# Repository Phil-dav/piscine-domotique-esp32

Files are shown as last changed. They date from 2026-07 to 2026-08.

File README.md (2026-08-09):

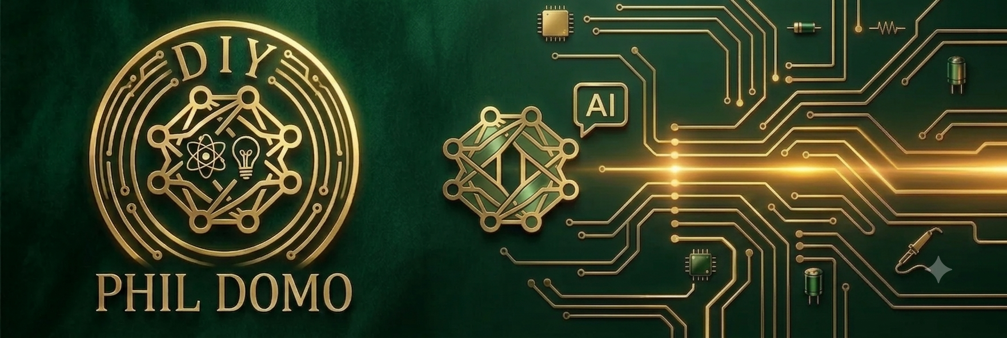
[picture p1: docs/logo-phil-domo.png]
Logo Phil Domo


# Gestion de filtration piscine — ESP32 / Rust





Système domotique embarqué qui pilote la pompe de filtration d'une piscine
familiale : température de l'eau, sécurités matérielles, planification
automatique, tableau de bord web, suivi cloud. Écrit en Rust sur ESP32
(`esp-idf-hal` / `esp-idf-svc`), portage et évolution d'un projet
C++/PlatformIO de référence.

## Sommaire

- [Aperçu](#aperçu)
- [Fonctionnalités](#fonctionnalités)
- [Architecture matérielle](#architecture-matérielle)
- [Organisation des fichiers](#organisation-des-fichiers)
- [Démarrage](#démarrage)
- [Tableau de bord web](#tableau-de-bord-web)
- [État du projet](#état-du-projet)
- [Licence](#licence)

## Aperçu

Le montage pilote une pompe de filtration selon trois modes sélectionnables
par un interrupteur physique — **AUTO** (durée de filtration calculée selon la
température de l'eau, dans une plage horaire configurable), **MANUEL**
(marche/arrêt à la demande) et **OFF** — avec un jeu de sécurités matérielles
(niveau d'eau, défaut moteur, anti-gel, canicule) qui prennent le pas sur
n'importe quel mode en cas de besoin. Un serveur web embarqué directement sur
l'ESP32 sert un tableau de bord en temps réel, sans dépendance à un service
externe pour fonctionner au quotidien.

## Fonctionnalités

- **Trois modes de fonctionnement** (interrupteur physique 3 positions) : AUTO,
  MANUEL (bouton ou page web), OFF.
- **Sécurités matérielles** : niveau d'eau, défaut moteur (disjoncteur),
  anti-gel, canicule, anti-claquement du relais (protection contre un cyclage
  trop rapide).
- **Task Watchdog** : tout blocage de plus de 5 s de la boucle principale
  déclenche un redémarrage automatique et journalisé, plutôt qu'un blocage
  total silencieux.
- **Tableau de bord web embarqué**, servi directement par l'ESP32 : température
  eau/air, humidité, état pompe, mode, position GPS, tension batterie, timeline
  colorée des modes de la journée (avec trace réelle de la marche pompe),
  marche forcée, réglage de la plage horaire, consultation des journaux
  (sessions pompe, bilans journaliers, alertes).
- **Journalisation persistante** (NVS) : sessions pompe, bilans journaliers,
  alertes, et compteurs du jour — survivent aux redémarrages.
- **Suivi cloud** vers [Adafruit IO](https://io.adafruit.com) : envoi groupé de
  toutes les mesures en une seule requête HTTP par cycle, dans un fil
  d'exécution dédié, jamais dans la boucle principale surveillée par le
  watchdog.
- **Horodatage GPS avec repli NTP** : heure fiable même sans réseau Wi-Fi.
- **Suivi de l'alimentation batterie/solaire** (en cours de câblage) : deux
  ponts diviseurs de tension pour surveiller la batterie 12V et la sortie
  régulée 5V d'un contrôleur de charge solaire.

## Architecture matérielle

| Bus / broche | Composant | Rôle |
| --- | --- | --- |
| I2C (GPIO21 SDA, GPIO22 SCL, 400 kHz) | AHT10 (0x38) | Température / humidité air |
| I2C | PCF8574 (0x21) | Expandeur de broches (relais, boutons, interrupteur de mode) |
| I2C | SSD1306 (0x3C) | Écran OLED de diagnostic |
| 1-Wire (GPIO4) | DS18B20 | Température de l'eau |
| UART2 (GPIO16 RX) | Module GPS | Horodatage et coordonnées |
| ADC1 (GPIO34) | Détecteur de niveau | Sécurité niveau d'eau |
| ADC1 (GPIO32, GPIO35) | Ponts diviseurs | Tension batterie 12V / sortie solaire 5V |

Détail du câblage du PCF8574 : P0 pilote le relais pompe, P3 le relais de
défaut système, P4/P5/P6 lisent respectivement le bouton écran et
l'interrupteur de mode (MANU/AUTO), P7 lit le retour de défaut moteur.

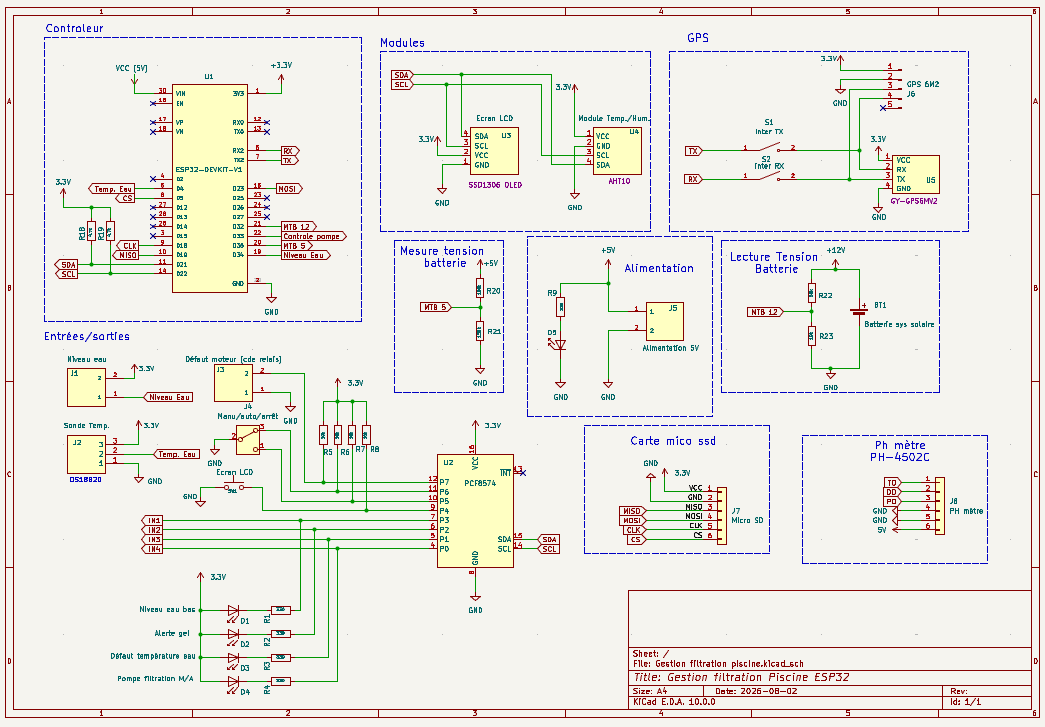
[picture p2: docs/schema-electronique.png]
Schéma électronique du montage


Schéma KiCad complet du montage. Il inclut des blocs anticipés dans la
conception (carte micro SD, pH-mètre PH-4502C, interrupteurs de logs série)
qui sont déjà câblés mais **pas encore pris en charge par le firmware
actuel** — schéma établi en amont de la réalisation, comme il est d'usage en
électronique.

Une [version vectorielle au format SVG](https://raw.githubusercontent.com/Phil-dav/piscine-domotique-esp32/main/docs/Gestion%20filtration%20piscine.svg)
est également disponible. Elle s'ouvre en plein écran dans le navigateur et se
zoome avec **Ctrl + molette** sans aucune perte de qualité, ce qui permet de lire
les références et les valeurs de chaque composant.

## Organisation des fichiers

Tout part de `main.rs`, qui orchestre les modules ci-dessous (capteurs, sécurité,
réseau, persistance) à chaque tour de la boucle principale.

```text
src/
├── main.rs             Point d'entrée : boucle principale, initialisation matérielle,
│                        orchestration de tous les modules ci-dessous
├── config.rs            Identifiants et réglages (Wi-Fi, Adafruit IO, broches) — non
│                        suivi par Git, voir config.example.rs pour le modèle
├── config.example.rs    Modèle de config.rs à copier et remplir localement
│
├── Capteurs
│   ├── aht10.rs          Driver du capteur AHT10 (température/humidité air)
│   ├── ds18b20.rs        Driver de la sonde DS18B20 (température eau, 1-Wire)
│   ├── gps.rs            Lecture des trames NMEA du module GPS
│   ├── niveau_eau.rs     Détection du niveau d'eau (sécurité)
│   └── batterie.rs       Lecture des tensions batterie/solaire (ADC)
│
├── Pilotage
│   ├── pcf8574.rs        Pilotage de l'expandeur I2C (relais, boutons, interrupteur)
│   ├── pompe.rs          État de la pompe (marche/arrêt, anti-claquement, compteurs)
│   ├── boost.rs          Marche/arrêt forcée temporaire
│   ├── filtration_auto.rs  Calcul de la durée de filtration (mode AUTO)
│   ├── securite.rs       Détection défaut moteur
│   └── historique_modes.rs  Historique coloré des modes pour la timeline du dashboard
│
├── Stockage et journalisation
│   ├── stockage.rs       Accès générique à la mémoire NVS (clé/valeur)
│   ├── journal.rs        Journaux persistés : sessions pompe, bilans, alertes
│   └── temps.rs          Conversion d'heure (UTC vers Europe/Paris, DST)
│
├── Réseau et interface
│   ├── wifi.rs           Connexion Wi-Fi
│   ├── web_server.rs     Serveur web embarqué : routes HTTP et API du dashboard
│   ├── adafruit_io.rs    Envoi des mesures vers Adafruit IO (cloud)
│   ├── etat_partage.rs   État partagé entre la boucle principale et le serveur web
│   ├── ecran.rs          Affichage sur l'écran OLED de diagnostic
│   ├── index.html        Page du tableau de bord
│   └── script.js         Logique JavaScript du tableau de bord
```

## Démarrage

1. Copier `src/config.example.rs` vers `src/config.rs` et y renseigner tes
   propres identifiants (Wi-Fi, clé Adafruit IO si tu utilises ce service —
   sinon laisse les valeurs par défaut, le programme continue de fonctionner
   sans Wi-Fi ni cloud).
2. Toolchain ESP-IDF `v5.5.3`, cible `xtensa-esp32-espidf` (voir
   `rust-toolchain.toml` et `.cargo/config.toml`).
3. `cargo check` pour vérifier, `cargo run` pour flasher (nécessite
   `espflash`).

## Tableau de bord web

Servi directement par l'ESP32 sur le réseau local (pas de service externe
requis) : mesures en temps réel, contrôle de la pompe et du mode, timeline
colorée de la journée, historique des sessions/alertes, réglage de la plage
de filtration.

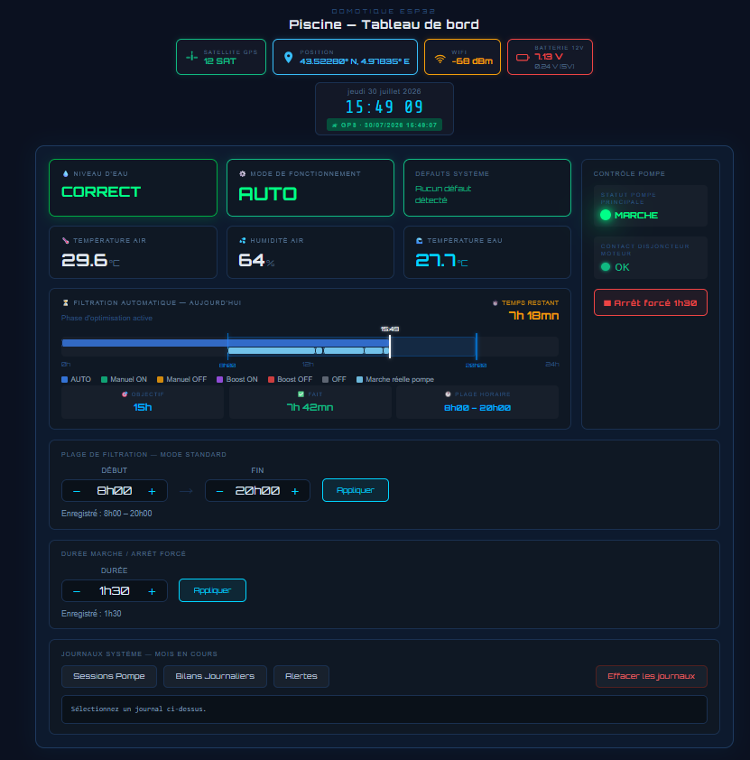
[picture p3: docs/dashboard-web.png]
Tableau de bord web


## État du projet

En développement actif — les fonctionnalités listées ci-dessus sont
opérationnelles et testées en conditions réelles. Chantiers en cours ou à
venir : carte SD pour un historique complet, capteur de courant sur
l'alimentation pompe, alarme de température du coffret électrique, alertes
push (ntfy.sh).

## Licence

Projet personnel, à but pédagogique et domestique.

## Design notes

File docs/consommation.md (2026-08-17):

# Bilan de consommation électrique

> Estimations basées sur les datasheets officiels des composants (sources
> citées pour chaque valeur), pas des mesures physiques. À confirmer un jour
> au multimètre/pince ampèremétrique si une vérification réelle est utile.

## Contexte

Suite à la conversion du PCB en 3,3V pour tout sauf le VIN de l'ESP32 et le
module 4 relais (voir la mémoire du projet sur le sujet), ce document répond à
la question : le régulateur 3,3V embarqué de l'ESP32 a-t-il assez de marge
pour alimenter tous les nouveaux composants raccordés dessus (écran OLED,
GPS, AHT10, PCF8574 et ses résistances/LED) ?

**Point important** : le rail 3,3V n'est pas une alimentation indépendante —
il est produit par le régulateur embarqué de l'ESP32 à partir du 5V d'entrée
(VIN). Le courant du rail 3,3V se retrouve donc intégralement dans le courant
tiré sur le 5V d'entrée (régulateur linéaire : courant d'entrée ≈ courant de
sortie, l'écart de tension est juste dissipé en chaleur). Le total réel à la
source d'alimentation 5V externe est donc : **module relais (direct 5V) +
courant du rail 3,3V (via le régulateur)** — pas une simple addition 5V + 3,3V
en parallèle.

## Rail 3,3V (via le régulateur embarqué de l'ESP32)

| Composant | Consommation | Source |
|---|---|---|
| ESP32-WROOM-32 (le module lui-même) | ~80-100 mA en fonctionnement normal, jusqu'à **240 mA en pointe** (émission Wi-Fi) | [Datasheet ESP32-WROOM-32](https://www.mouser.com/datasheet/2/891/esp-wroom-32_datasheet_en-1223836.pdf) |
| Module GPS GY-NEO6MV2 (NEO-6M) | ~45 mA en poursuite (jusqu'à ~67 mA au démarrage à froid) | [datasheethub.com](https://www.datasheethub.com/gy-neo6mv2-flight-control-gps-module/) |
| Écran OLED SSD1306 128×64 | ~20-25 mA typique (jusqu'à ~50 mA si affichage presque entièrement allumé) | [Datasheet SSD1306 (Adafruit)](https://cdn-shop.adafruit.com/datasheets/SSD1306.pdf) |
| AHT10 | ~1 mA max en mesure (négligeable, µA au repos) | [Datasheet AOSONG/ASAIR](https://server4.eca.ir/eshop/AHT10/Aosong_AHT10_en_draft_0c.pdf) |
| PCF8574 (puce elle-même) | ~10 µA en veille (négligeable) | [Datasheet TI](https://www.ti.com/product/PCF8574) |
| 4 résistances de tirage P4-P7 (10 kΩ vers 3,3V) | 0,33 mA chacune → **1,3 mA** au total | Calcul (loi d'Ohm, valeurs confirmées dans le schéma KiCad) |
| 4 LED D1-D4 (résistances série R1-R4 = 330 Ω) toutes allumées ensemble | ~4 mA chacune → **~16 mA** au total | Calcul (loi d'Ohm, seuil LED estimé ~2V) |

**Sous-total rail 3,3V** : ~190 mA en fonctionnement normal, jusqu'à **~330 mA en pointe** (Wi-Fi + GPS + écran chargé simultanément).

## Rail 5V direct (ne passe pas par le régulateur 3,3V)

| Composant | Consommation | Source |
|---|---|---|
| Module 4 relais (Songle SRD-05VDC-SL-C), les 4 énergisés en même temps | 71,4 mA par relais → **~285 mA** au total | [Datasheet SRD-05VDC-SL-C](https://www.circuitbasics.com/wp-content/uploads/2015/11/SRD-05VDC-SL-C-Datasheet.pdf) |

En pratique, il est rare que les 4 relais soient activés exactement en même
temps (pompe + ventilation coffret sont les deux usages prévus à ce jour) —
cette valeur est un plafond, pas la consommation habituelle.

## Total à la source d'alimentation 5V externe

| Scénario | Calcul | Total |
|---|---|---|
| Fonctionnement normal | 3,3V (~190 mA, via régulateur) + relais (2 relais actifs, ~140 mA) | **~330 mA** |
| Pire cas (tout en pointe en même temps) | 3,3V (~330 mA) + relais (4 actifs, ~285 mA) | **~615 mA** |

## Marge disponible

Le régulateur 3,3V embarqué de l'ESP32 (selon le modèle de carte, à vérifier
par le marquage sur le petit boîtier près du connecteur USB) :

- **AMS1117-3.3** (le plus courant) : 1 A max → la pointe de ~330 mA sur le
  rail 3,3V reste à **33% de sa capacité**, largement confortable.
- **ME6211C33** (SOT23-5, sur certains clones plus compacts) : 500 mA max →
  ~330 mA en pointe représente **66% de sa capacité** — toujours dans les
  clous, marge plus serrée.

**Conclusion (analysée le 04/08/2026)** : marge confortable dans les deux cas
pour la configuration actuelle. Pas besoin d'une alimentation 3,3V externe
séparée pour l'instant. À revérifier si un composant supplémentaire important
est ajouté un jour (le pH-mètre PH-4502C, par exemple, consomme lui-même très
peu — quelques mA — donc ne changerait pas cette conclusion).

Pensez aussi à vérifier que votre bloc d'alimentation 5V externe (celui qui
alimente le J5 "Alimentation 5V") est bien dimensionné pour au moins ~700 mA
avec de la marge, pour couvrir le pire cas ci-dessus sans être à sa limite.

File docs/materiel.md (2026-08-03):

# Matériel utilisé

Une fiche par composant du montage : rôle dans le projet, lien vers la fiche
technique (datasheet) officielle du fabricant, et photo/schéma quand disponible.

Voir aussi le [schéma électronique complet](schema-electronique.png) et le
[tableau d'architecture matérielle](../README.md#architecture-matérielle) dans le
README, plus synthétique.

## AHT10

**Rôle** : température et humidité de l'air (I2C, adresse 0x38).

**Fiche technique** : [AHT10 — datasheet (PDF)](https://components101.com/sites/default/files/component_datasheet/AHT10.pdf)

## PCF8574

**Rôle** : expandeur de broches I2C (adresse 0x21) — pilotage du relais pompe et
du relais de défaut système, lecture des boutons et de l'interrupteur de mode,
lecture du défaut moteur.

**Fiche technique** : [PCF8574 — datasheet officielle NXP (PDF)](https://www.nxp.com/docs/en/data-sheet/PCF8574_PCF8574A.pdf)

## SSD1306

**Rôle** : contrôleur de l'écran OLED de diagnostic (I2C, adresse 0x3C).

**Fiche technique** : [SSD1306 — datasheet officielle Solomon Systech (PDF)](https://cdn-shop.adafruit.com/datasheets/SSD1306.pdf)

## DS18B20

**Rôle** : sonde de température de l'eau (bus 1-Wire, GPIO4).

**Fiche technique** : [DS18B20 — page produit et datasheet officielle Analog Devices/Maxim](https://www.analog.com/en/products/ds18b20.html)

## Module GPS — GY-NEO6MV2 (puce u-blox NEO-6M)

**Rôle** : horodatage et coordonnées GPS (UART2, GPIO16 RX).

Carte de rupture (breakout board) générique GY-NEO6MV2/GY-GPS6MV2, basée sur la
puce u-blox NEO-6M — existe en variante 4 ou 5 broches (la 5ᵉ broche ajoute
généralement une sortie PPS, non utilisée dans ce projet).

**Fiche technique** : [NEO-6 — datasheet officielle u-blox (PDF)](https://content.u-blox.com/sites/default/files/products/documents/NEO-6_DataSheet_(GPS.G6-HW-09005).pdf)

## Détecteur de niveau d'eau — poire à flotteur, contact sec

**Rôle** : sécurité niveau d'eau (ADC1, GPIO34).

Poire de niveau à flotteur, contact sec NO/NC (normalement ouvert/fermé) — composant
purement mécanique, pas d'électronique embarquée. Contact ouvert/fermé lu côté
firmware via une lecture ADC avec seuils et hystérésis (`niveau_eau.rs`), le même
principe s'applique quel que soit le modèle exact choisi. Pas de référence précise
retenue pour l'instant — n'importe quelle poire générique à contact sec NO/NC fait
l'affaire (ex. modèles disponibles chez ManoMano, Assainipompes.fr,
Pompes-direct.com).

**Fiche technique** : composant mécanique générique, pas de datasheet dédiée
nécessaire — juste vérifier le type de contact (NO/NC) et le courant max supporté
(5A largement suffisant, le contact ne pilote qu'une entrée logique).

## PH-4502C

**Rôle** : mesure du pH de l'eau — module **amovible**, pas branché en permanence
(voir la mémoire du projet : vérification ponctuelle sous tension, résistance de
tirage 200 kΩ-1 MΩ prévue sur l'ADC pour détecter branchement/débranchement). Déjà
en main (testé avec Arduino Uno), câblage sur l'ESP32 et mise à jour du schéma
électronique restants à faire.

Alimentation 5±0,2V, sortie analogique 0-5V (pont diviseur nécessaire vers l'ADC
ESP32, limité à 3,3V), électrode à connecteur BNC, 2 potentiomètres de calibration
à bord. Temps de réponse ≤ 5s, stabilisation ≤ 60s.

**Fiche technique** : [page produit officielle diymore.cc](https://www.diymore.cc/products/diymore-liquid-ph-value-detection-detect-sensor-module-monitoring-control-for-arduino-m) —
voir aussi ce [guide d'utilisation et de calibration détaillé](https://raaflahar.medium.com/ph-4502c-sensor-diymore-how-to-use-and-calibrate-using-arduino-uno-r3-3afc2b96631).

**Photo** : test avec Arduino Uno, voir `c:\rust\Images vidéos\PH metre arduino.jpeg`.

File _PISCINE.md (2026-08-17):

# Automate de piscine — projet principal

Paquet : `pcf8574`
Carte : ESP32 classique (bicœur, Xtensa), cible `xtensa-esp32-espidf`.
Port série : **COM4**

## Ce que fait ce dossier

Le pilotage complet de la filtration : lecture des températures (eau et air),
calcul du temps de filtration nécessaire, commande du relais de pompe, sécurités
(niveau d'eau, défaut moteur, anti-gel, canicule), écran embarqué, horloge GPS,
tableau de bord web servi par la carte elle-même, et envoi vers Adafruit IO.

C'est le seul dossier en production : il tourne en permanence.

## Commandes

```
flash piscine      # téléverse (C:\rust\3, cargo run)
connect piscine    # capture le port série vers C:\rust\3\logs
```

Les journaux sont écrits en deux fichiers par capture :
`log_piscine_<date>_fonctionnement.txt` (lignes `I`) et `..._defauts.txt`
(lignes `W` et `E`).

## À savoir avant de toucher au code

**Incrémenter `VERSION_FIRMWARE` dans `src/config.rs` avant chaque flash.** C'est
le seul moyen de savoir, en lisant un journal, quelle version tournait.

**Un arrêt d'urgence câblé, indépendant de l'ESP32**, coupe l'alimentation du
relais de puissance. Les délais et sécurités logiciels relèvent donc du confort
de fonctionnement, pas de la sécurité des personnes.

`src/config.rs` contient les identifiants Wi-Fi et les clés Adafruit : il n'est
pas versionné. `config.example.rs` en tient lieu de modèle.

## Documentation

- `README.md` — installation, matériel, mise en route
- `docs/etat-projet.md` — état des lieux, réécrit à chaque bilan
- `docs/logique-pilotage-pompe.md` — la pyramide de priorité des décisions
- `docs/these-wifi-esp32*.md` — le récit de l'enquête sur l'instabilité réseau
- `.claude/skills/` — procédures de compilation, de diagnostic et de portage

## État au 16/08/2026

Version **1.9** en service. La **2.0** est compilée et vérifiée mais **pas encore
flashée** : elle corrige la reconnexion Wi-Fi, qui n'exécutait rien
(`disconnect()` manquant avant `connect()`), et espace le journal série de 2 s à
10 s avec déclenchement immédiat sur changement d'état.

Voir `c:\rust\5` — l'espion Wi-Fi, construit pour observer cette carte depuis
l'extérieur.

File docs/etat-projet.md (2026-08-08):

# État du projet — point du 08/08/2026

> Ce fichier est mis à jour automatiquement à chaque fois que je fais un point
> avec l'utilisateur sur l'avancement du projet. Le contenu ci-dessous est
> remplacé intégralement à chaque nouveau point, ce n'est pas un historique.

## La journée du 08/08 : enquête Wi-Fi complète

Toute la session a été consacrée à une panne réseau, puis à sa cause racine.
Trois versions de firmware ont été flashées dans la journée (1.1, 1.2, 1.3).

### La panne constatée

À 09h48, le signal chute à -77 dBm. Suivent **1h30 de dashboard totalement
injoignable**, avec 5 réinitialisations complètes du pilote Wi-Fi qui ne
rétablissent rien. La Livebox voyait pourtant la carte comme connectée, avec
son IP. Seul un **reset manuel à 11h29** a rétabli le service.

Point important : ce n'était **pas** un plantage du firmware. Aucun
redémarrage, aucun panic, RAM stable (142-163 Ko), capteurs actifs pendant
tout l'épisode.

### Cause racine n°1 — le contrôle de santé Wi-Fi était trop faible

`is_connected()` d'esp-idf-svc ne reflète **que l'association 802.11** : un
simple drapeau alimenté par les événements du pilote. Il ne prouve à aucun
moment qu'un paquet circule.

Le piège : la logique de reconnexion de `main.rs` est gardée par
`if wifi_connecte { ... } else { ...reconnexion... }`. Tant que
`is_connected()` répond `true`, **aucun mécanisme de secours ne peut se
déclencher**. La carte pouvait donc rester indéfiniment « associée mais
morte », ce qui est exactement ce qui s'est produit.

Corrigé en 1.2 :

- contrôle de santé passé à `is_up()` **plus** vérification qu'une IP est
  réellement attribuée ;
- nouveau module `surveillance_reseau.rs` : sonde active qui ping la
  passerelle toutes les 60 s, dans un fil dédié (jamais dans la boucle
  principale, voir le piège des appels réseau bloquants) ;
- escalade en deux temps : réinitialisation du pilote après 5 min sans
  joignabilité, `esp_restart()` après 15 min, avec alerte `RESEAU_ZOMBIE`
  journalisée ;
- garde-fou anti-boucle : l'escalade exige qu'**au moins un ping ait réussi
  depuis le démarrage**. Une passerelle qui ignore l'ICMP ne peut donc jamais
  provoquer de redémarrages en cascade.

### Cause racine n°2 — la veille modem, jamais désactivée

Découverte par la mesure, pas par la lecture du code. Aucun réglage
d'économie d'énergie n'existait dans le projet : la carte utilisait donc le
défaut ESP-IDF en mode station, `WIFI_PS_MIN_MODEM`.

Corrigé en 1.3 : `esp_wifi_set_ps(WIFI_PS_NONE)` dans `wifi.rs`, appelé au
démarrage **et réappliqué après chaque `stop()`/`start()` du pilote**.
Application confirmée par le journal de boot (`wifi:Set ps type: 0`).

**Résultat mesuré, test A/B correctement contrôlé** — même matériel, même
signal, même charge (2 dashboards ouverts, ~1 requête/s), une seule ligne de
code d'écart :

| En charge | v1.2 | v1.3 |
| --- | --- | --- |
| Ping — perte de paquets | 75 % | **0 %** |
| Ping — latence moyenne | 1 627 ms | **9 ms** |
| HTTP — pire cas | échec à 20 s, puis 7,38 s | **0,131 s** |

À vide également : ping moyen 128 ms → 9 ms, et surtout disparition de la
gigue (45-253 ms → 6-12 ms).

### Correctif annexe côté navigateur

`fetch('/sensors')` n'avait aucun délai maximal. Une requête restée en
suspens bloquait définitivement le verrou `isFetching`, figeant le dashboard
jusqu'à un rechargement manuel. Ajout d'un `AbortController` à 8 s dans
`script.js`. Ce n'était pas la cause de la panne, seulement une fragilité
réelle.

## Ce qui reste ouvert

- **La panne « associée mais injoignable » n'est pas démontrée résolue.** Elle
  ne s'est pas reproduite depuis, donc la sonde et le redémarrage automatique
  n'ont jamais eu l'occasion de se déclencher en conditions réelles. La cause
  racine n°2 est très probablement la même, mais ça reste à confirmer sur
  plusieurs jours.
- **Budget de sockets très serré** (analysé, non corrigé) :
  `CONFIG_LWIP_MAX_SOCKETS = 10` pour tout le programme, dont 7 consommés par
  le seul serveur web (4 clients + 3 internes), plus NTP, Adafruit IO et la
  nouvelle sonde ping. On est **au plafond en pointe**. Par ailleurs
  `esp-idf-svc` limite à 4 connexions clients là où ESP-IDF lui-même utilise
  7 par défaut, alors qu'un navigateur en ouvre jusqu'à 6 en parallèle.
  Proposé pour une 1.4 : `CONFIG_LWIP_MAX_SOCKETS=16` et
  `max_open_sockets: 7`.

## À faire, par ordre de proximité

**Suite immédiate** :

- Laisser tourner la 1.3 plusieurs jours et surveiller le retour éventuel de
  l'indisponibilité longue.
- Décider si on applique la 1.4 (sockets) — moins urgent depuis que la
  latence est retombée à 90 ms.

**Chantier en pause** :

- Provisioning Wi-Fi (portail captif) — plus urgent depuis l'abandon du
  dashboard simplifié, reste utile pour la cave.

**Chantiers matériels, rien codé, câblage à faire** :

- Capteur de courant TA12-100 pour la pompe (remplace le relais miroir) — la
  pince de mesure de courant manque toujours pour calibrer avant de câbler.
- Ventilation active du coffret (relais P1 libre, vérif via INA219) — le
  coffret physique n'existe pas encore.
- Carte micro SD (broches confirmées CS=5/CLK=18/MISO=19/MOSI=23).
- Interrupteur logs série (GPIO27, schéma KiCad finalisé) — code de lecture
  GPIO27 pas encore écrit.
- pH-mètre (PH-4502C) — pont diviseur 5V→3,3V + résistance de tirage à
  monter, code de détection présence/absence à écrire.
- Conversion 3,3V du PCB (plan validé le 04/08, pas encore câblé).
- Alimentation batterie/solaire (idée, pas décidée) — à noter : la
  désactivation de la veille modem augmente la consommation moyenne, à
  reconsidérer si ce chantier démarre.

**Discord / présentation** :

- Synthèse narrative de l'enquête Wi-Fi à écrire pour le Discord, une fois le
  problème considéré résolu à ~100 % — avec les fausses pistes assumées.

**Idée non décidée, juste en mémoire** :

- Traduction anglaise de la doc à terme — pas de date.

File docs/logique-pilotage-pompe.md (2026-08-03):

# Logique de pilotage de la pompe de filtration

Ce document explique **comment et pourquoi la pompe démarre ou s'arrête**, dans
le firmware ESP32 (`src/main.rs` et modules associés). Il ne reprend pas
l'architecture matérielle générale (voir le [README](../README.md) pour ça) —
uniquement la logique de décision marche/arrêt.

Le code ne raisonne pas comme "trois modes indépendants" : il empile plusieurs
niveaux de priorité, où les sécurités passent **au-dessus** du mode
sélectionné, quel qu'il soit. Ce document suit donc cet ordre, du plus
prioritaire (peut couper la pompe quoi qu'il arrive) au moins prioritaire
(logique propre à chaque mode).

## Vue d'ensemble : la pyramide de priorité

Du haut (prioritaire) vers le bas :

1. **Anti-claquement** (protection relais/moteur) — `pompe.rs`
2. **Sécurités process** (niveau d'eau, défaut moteur) — `niveau_eau.rs`, `securite.rs`
3. **Anti-gel absolu** (température < 2°C) — outrepasse même le mode OFF
4. **Mode sélectionné** (OFF / MANUEL / AUTO) — `main.rs`, `boost.rs`, `filtration_auto.rs`
5. **Application finale** au relais — `pompe.rs`

Chaque niveau peut imposer l'arrêt (ou, pour l'anti-gel, forcer la marche)
indépendamment de ce que demandent les niveaux en dessous.

## 1. Anti-claquement (`pompe.rs`)

Protection purement matérielle du relais et du moteur, indépendante de toute
logique métier. Si la pompe change d'état plus de **4 fois en 2 minutes**
(fenêtre glissante volontairement large, pour intercepter aussi un cyclage
plus lent — ex. lors d'une variation rapide de température pendant un orage),
elle est **bloquée de force pendant 5 minutes**, quel que soit le mode ou les
autres sécurités.

## 2. Sécurités process

Deux conditions forment `systeme_sur` (`niveau_ok && !securite_moteur.actif()`).
Si `systeme_sur` est `false`, la pompe est coupée immédiatement.

### Niveau d'eau bas (`niveau_eau.rs`)

Lecture ADC avec **hystérésis à deux seuils** (un seuil bas pour couper, un
seuil haut plus élevé pour réarmer — évite les allers-retours si le niveau
oscille pile sur un seul seuil) et un **filtre temporel anti-vaguelettes**
(3 à 5 secondes de confirmation avant de basculer l'état, pour ignorer un
remous passager sans réagir trop lentement à un vrai manque d'eau).

Cas particulier du tout premier relevé après un démarrage : appliqué
**immédiatement**, sans attendre le délai de confirmation — ni excès de
prudence (bloquer sans raison), ni excès de confiance (laisser tourner à sec
le temps que le filtre se stabilise). Voir le commentaire dans
`NiveauEau::mettre_a_jour`.

### Défaut moteur (`securite.rs`)

Contact du disjoncteur lu via le PCF8574 (contact fermé = normal, contact
ouvert = défaut). Anti-rebond de 200 ms avant confirmation. **Une fois
confirmé, le défaut reste verrouillé** même si le contact se referme tout
seul — un réarmement manuel explicite (page web) est nécessaire. Volontaire :
un défaut moteur ne doit jamais se lever tout seul sans qu'un humain ait
vérifié la cause.

## 3. Anti-gel absolu

Si la température de l'eau descend sous **2°C**, la pompe est forcée en
marche pour protéger la tuyauterie — **y compris en mode OFF**. C'est la
seule règle qui outrepasse le mode sélectionné lui-même (les sécurités des
niveaux 1 et 2 restent malgré tout prioritaires par-dessus).

## 4. Mode sélectionné

### Mode OFF

`demande_pompe = false` systématiquement, sauf l'anti-gel absolu ci-dessus.

### Mode MANUEL

`demande_pompe = demande_manuelle` — une simple variable pilotée par le
bouton physique ou la page web. Aucune logique automatique : marche/arrêt à
la demande, toujours soumis aux sécurités des niveaux 1 et 2.

### Mode AUTO

Le plus élaboré, avec plusieurs couches :

1. **Calcul de l'objectif d'heures du jour** (`filtration_auto.rs`, fonction
   `heures_cibles`), selon la température de l'eau, avec 5 régimes à
   hystérésis (pour éviter les oscillations aux seuils) :
   - **Anti-gel** (< 4°C) : 24h/24, plage horaire élargie à toute la journée.
   - **Canicule** (> 28,5°C) : 24h/24 aussi.
   - **Hiver** (< 9,5°C, sans atteindre l'anti-gel) : 2h fixes, plage 10h-16h.
   - **Normal** (10,5°C à 28,5°C) : formule température/2, +1h bonus si l'eau
     dépasse 24°C.
2. **Fiabilité de l'objectif** (`objectif_connu`) : si la sonde DS18B20 ne
   répond pas, pas de filtration AUTO plutôt que de filtrer « à l'aveugle ».
3. **Verrou journalier** (`filtration_terminee_aujourdhui`) : une fois
   l'objectif d'heures atteint, la pompe ne redémarre plus ce jour-là, même
   si l'objectif recalculé change ensuite (ex. chute de température lors
   d'un orage) — évite un cyclage marche/arrêt/marche.
4. **Plage horaire** (`dans_plage`) : la pompe ne démarre en AUTO que dans la
   fenêtre configurée (par défaut 8h-20h, sauf anti-gel/canicule qui
   l'étendent à 24h/24).
5. **Boost** (`boost.rs`) : disponible uniquement en AUTO, marche/arrêt
   forcée temporaire (30 min à 8h, réglable par paliers de 30 min) qui prend
   le pas sur toute la logique ci-dessus pendant sa durée, puis rend
   automatiquement la main.

En résumé : `demande_pompe` (AUTO) = `objectif_connu && !filtration_terminee_aujourdhui && dans_plage`
(ou l'inverse imposé par le boost s'il est actif).

## 5. Application finale (`pompe.rs`)

Quel que soit le mode, la `demande_pompe` calculée passe dans
`GestionPompe::mettre_a_jour(demande, systeme_sur)`, qui applique dans
l'ordre : blocage anti-claquement en cours → sécurité (`systeme_sur`) → et
seulement alors, applique réellement la demande et compte la transition pour
l'anti-claquement.

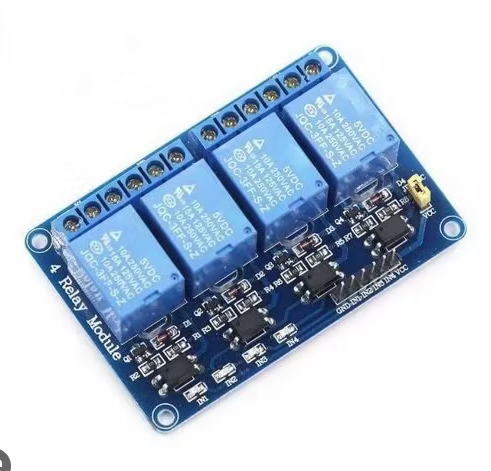
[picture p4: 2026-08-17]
docs/Module relais.png

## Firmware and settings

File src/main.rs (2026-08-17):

mod adafruit_io;
mod aht10;
mod batterie;
mod boost;
mod config;
mod ds18b20;
mod ecran;
mod etat_partage;
mod filtration_auto;
mod filtre_mode;
mod gps;
mod historique_modes;
mod journal;
mod niveau_eau;
mod pcf8574;
mod pompe;
mod securite;
mod stockage;
mod surveillance_reseau;
mod temps;
mod web_server;
mod wifi;

use chrono::{Datelike, Timelike};
use core::cell::RefCell;
use embedded_hal_bus::i2c::RefCellDevice;
use esp_idf_svc::eventloop::EspSystemEventLoop;
use esp_idf_svc::hal::adc::oneshot::{
    config::{AdcChannelConfig, Calibration},
    AdcChannelDriver, AdcDriver,
};
use esp_idf_svc::hal::adc::{attenuation, Resolution};
use esp_idf_svc::hal::delay::{Delay, FreeRtos};
use esp_idf_svc::hal::gpio::{AnyIOPin, PinDriver, Pull};
use esp_idf_svc::hal::i2c::{I2cConfig, I2cDriver};
use esp_idf_svc::hal::peripherals::Peripherals;
use esp_idf_svc::hal::reset::ResetReason;
use esp_idf_svc::hal::task::watchdog;
use esp_idf_svc::hal::uart::{config::Config as UartConfig, UartDriver};
use esp_idf_svc::hal::units::{FromValueType, Hertz};
use esp_idf_svc::nvs::EspDefaultNvsPartition;
use esp_idf_svc::sntp::{EspSntp, SyncStatus};
use esp_idf_svc::wifi::{BlockingWifi, EspWifi};
use log::{info, warn};
use one_wire_bus::OneWire;
use ssd1306::{prelude::*, I2CDisplayInterface, Ssd1306};
use std::time::{Duration, Instant};

const CLE_BOOST_MIN: &str = "boost_min";
const CLE_DERNIER_HORODATAGE: &str = "dernier_ts";
/// Horodatage (epoch UTC) du dernier redémarrage déclenché par le chien de garde
/// réseau. Persisté pour que le garde-fou anti-boucle survive au redémarrage qu'il
/// limite — en RAM, il serait remis à zéro à chaque fois et ne servirait à rien.
const CLE_DERNIER_REBOOT_AUTO: &str = "reboot_auto_ts";
/// En dessous de ce seuil, un redémarrage juste après une coupure d'alimentation
/// (POWERON/BROWNOUT) ressemble à une micro-coupure secteur plutôt qu'à un arrêt
/// volontaire prolongé — seuil choisi par l'utilisateur, ajustable ici si besoin.
const SEUIL_COUPURE_COURTE_MIN: i64 = 2;

/// Traduit la raison de redémarrage ESP-IDF en texte court pour le journal des alertes.
fn raison_reset_texte(raison: ResetReason) -> &'static str {
    match raison {
        ResetReason::PowerOn => "ALIMENTATION",
        ResetReason::Brownout => "SOUS_TENSION",
        ResetReason::Panic => "PANIC",
        ResetReason::TaskWatchdog => "WATCHDOG_TACHE",
        ResetReason::InterruptWatchdog => "WATCHDOG_INTERRUPTION",
        ResetReason::Watchdog => "WATCHDOG",
        ResetReason::Software => "LOGICIEL",
        ResetReason::ExternalPin => "BOUTON_RESET",
        ResetReason::DeepSleep => "REVEIL_VEILLE",
        ResetReason::Unknown => "INCONNUE",
        _ => "AUTRE",
    }
}

/// Valeur numérique du mode envoyée à Adafruit IO. Décalée à 2/3/4 (au lieu de
/// 0/1/2) pour ne jamais chevaucher l'échelle 0/1 (arrêt/marche) de la pompe
/// sur le même graphique — sinon impossible de distinguer "pompe en marche"
/// de "mode manuel" quand les deux valent 1 (constaté par l'utilisateur le
/// 30/07/2026 en comparant les deux courbes).
fn mode_vers_valeur_cloud(mode: &etat_partage::Mode) -> u8 {
    match mode {
        etat_partage::Mode::Off => 2,
        etat_partage::Mode::Manuel => 3,
        etat_partage::Mode::Auto => 4,
    }
}

fn main() -> anyhow::Result<()> {
    esp_idf_svc::sys::link_patches();
    esp_idf_svc::log::EspLogger::initialize_default();
    if !config::LOGS_SERIE_ACTIFS {
        log::set_max_level(log::LevelFilter::Off);
    }

    // Capturée le plus tôt possible : c'est la seule fenêtre où ESP-IDF garantit que
    // cette info reflète encore le redémarrage qui vient de se produire.
    let raison_reset = ResetReason::get();

    info!(
        "Démarrage du programme — firmware v{}",
        config::VERSION_FIRMWARE
    );

    let debut_programme = Instant::now();

    let peripherals = Peripherals::take()?;
    let sys_loop = EspSystemEventLoop::take()?;
    let nvs = EspDefaultNvsPartition::take()?;
    let mut stockage = stockage::Stockage::ouvrir(nvs.clone())?;
    // Journaux (sessions pompe, bilans, alertes) : historique borné persisté en NVS,
    // partagé entre la boucle principale (écriture) et le serveur web (lecture/effacement).
    let journal = std::sync::Arc::new(parking_lot::Mutex::new(journal::Journal::ouvrir(
        nvs.clone(),
    )?));

    // --- I2C (AHT10 + écran + PCF8574) ---
    // 400 kHz (Fast Mode) au lieu de 100 kHz : les 3 périphériques le supportent, et ça
    // réduit d'autant le temps de blocage de chaque transaction I2C — notamment le flush
    // de l'écran OLED (~1 Ko de données), qui est la plus grosse transaction du bus.
    let sda = peripherals.pins.gpio21;
    let scl = peripherals.pins.gpio22;
    let i2c_config = I2cConfig::new().baudrate(400.kHz().into());
    let i2c = I2cDriver::new(peripherals.i2c0, sda, scl, &i2c_config)?;
    let i2c_partage = RefCell::new(i2c);

    // --- 1-Wire (DS18B20) ---
    let one_wire_pin = PinDriver::input_output_od(peripherals.pins.gpio4, Pull::Up)?;
    let mut one_wire =
        OneWire::new(one_wire_pin).map_err(|e| anyhow::anyhow!("Erreur init 1-Wire : {:?}", e))?;
    let mut delay = Delay::new_default();

    // --- GPS (UART2, trames NMEA) ---
    // Tampon RX agrandi (défaut = 256 octets) : le module GPS émet en continu, mais
    // `gps.mettre_a_jour()` n'est appelé qu'une fois par itération de la boucle principale,
    // qui peut prendre 2-3 s (conversion DS18B20, delay final...). Avec un tampon trop petit,
    // ces quelques secondes suffisent à le faire déborder et à corrompre des trames NMEA.
    let gps_uart_config = UartConfig::default()
        .baudrate(Hertz(config::GPS_BAUDRATE))
        .rx_fifo_size(2048);
    let gps_uart = UartDriver::new(
        peripherals.uart2,
        peripherals.pins.gpio17, // TX (non utilisé, le module GPS n'écoute rien)
        peripherals.pins.gpio16, // RX
        Option::<AnyIOPin>::None,
        Option::<AnyIOPin>::None,
        &gps_uart_config,
    )?;
    let mut gps = gps::Gps::new(gps_uart);

    // --- Sécurité pompe : niveau d'eau (GPIO34, ADC1) ---
    // GPIO33 (ex-feedback relais miroir) est libre : réservé au futur capteur de courant.
    let adc1 = AdcDriver::new(peripherals.adc1)?;
    let niveau_config = AdcChannelConfig {
        attenuation: attenuation::DB_12,
        resolution: Resolution::Resolution12Bit,
        calibration: Default::default(),
    };
    let mut niveau_chan = AdcChannelDriver::new(&adc1, peripherals.pins.gpio34, &niveau_config)?;

    // --- Ponts diviseurs batterie/solaire (voir batterie.rs et la mémoire
    // projet-alimentation-batterie-solaire pour le détail des résistances) ---
    // Calibration::Line (basée sur les eFuses de la puce) au lieu de None : ces
    // deux lectures servent à suivre une vraie tension, contrairement au niveau
    // d'eau qui n'est qu'un seuil, donc la précision compte davantage ici.
    let batterie_config = AdcChannelConfig {
        attenuation: attenuation::DB_12,
        resolution: Resolution::Resolution12Bit,
        calibration: Calibration::Line,
    };
    let mut mtb12_chan = AdcChannelDriver::new(&adc1, peripherals.pins.gpio32, &batterie_config)?;
    let mut mtb5_chan = AdcChannelDriver::new(&adc1, peripherals.pins.gpio35, &batterie_config)?;

    FreeRtos::delay_ms(100);

    // Non bloquant : un PCF8574 injoignable au démarrage (composant absent ou en panne)
    // ne doit pas empêcher le reste du programme (Wi-Fi, dashboard, autres capteurs) de
    // démarrer. `Sorties::default()` correspond à l'état que `init` aurait écrit en cas
    // de succès (tout inactif) — la pompe et le relais défaut restent commandés à
    // l'arrêt côté logiciel, prêts à être réappliqués dès que le composant répond.
    let mut sorties = pcf8574::init(&i2c_partage).unwrap_or_else(|e| {
        warn!(
            "PCF8574 : initialisation échouée, composant absent ou injoignable : {:?}",
            e
        );
        pcf8574::Sorties::default()
    });

    let interface = I2CDisplayInterface::new(RefCellDevice::new(&i2c_partage));
    let mut display = Ssd1306::new(interface, DisplaySize128x64, DisplayRotation::Rotate0)
        .into_buffered_graphics_mode();

    // L'écran est un confort de diagnostic, pas une fonction vitale : s'il refuse de
    // s'initialiser (bus I2C pas encore stable à froid, écran pas alimenté à temps...),
    // le programme continue quand même sans lui plutôt que de tout arrêter comme avant
    // (Wi-Fi et pompe doivent fonctionner même si l'écran a un problème).
    let mut ecran_disponible = false;
    for tentative in 1..=5 {
        match display.init() {
            Ok(()) => {
                ecran_disponible = true;
                break;
            }
            Err(e) => {
                warn!("Écran OLED : échec init (essai {}/5) : {:?}", tentative, e);
                FreeRtos::delay_ms(200);
            }
        }
    }
    if !ecran_disponible {
        warn!("Écran OLED indisponible — le programme continue sans affichage.");
    }

    // --- Wi-Fi ---
    if ecran_disponible {
        if let Err(e) = ecran::afficher_connexion(&mut display) {
            warn!("Écran OLED : erreur d'affichage (ignorée) : {:?}", e);
        } else if let Err(e) = display.flush() {
            warn!("Écran OLED : erreur de flush (ignorée) : {:?}", e);
        }
    }

    // --- État partagé (toujours créé, utilisé même sans Wi-Fi pour piloter la pompe) ---
    let etat = etat_partage::nouveau();

    let mut wifi: Option<BlockingWifi<EspWifi<'static>>> = None;
    let mut ip_texte = "Wi-Fi désactivé (test)".to_string();
    // `_sntp`/`_server` doivent rester en vie tout le programme (sinon ils s'arrêtent) :
    // liés ici pour ne pas être supprimés à la fin de ce bloc.
    let mut sntp = None;
    let mut _server = None;

    if config::WIFI_ACTIF {
        // Non bloquant : avant ce correctif, un échec de connexion au tout premier
        // démarrage (réseau introuvable, mauvais mot de passe, box en panne) arrêtait
        // tout le programme via `?` — donc plus de pompe, plus de sécurités, plus
        // d'écran, alors qu'aucune de ces fonctions ne dépend du Wi-Fi. `wifi` reste
        // `Option<...>` et le reste du programme sait déjà gérer son absence (boucle
        // principale, reconnexion, dashboard) — seul ce point d'entrée restait fatal.
        match wifi::connecter(peripherals.modem, sys_loop, nvs) {
            Ok(w) => {
                // Synchronisation horaire de secours (utilisée seulement si le GPS n'a pas de fix frais).
                sntp = Some(EspSntp::new_default()?);

                let ip_info = w.wifi().sta_netif().get_ip_info()?;
                ip_texte = ip_info.ip.to_string();

                if ecran_disponible {
                    if let Err(e) =
                        ecran::afficher_connecte(&mut display, &ip_texte, w.wifi().get_rssi().ok())
                    {
                        warn!("Écran OLED : erreur d'affichage (ignorée) : {:?}", e);
                    } else if let Err(e) = display.flush() {
                        warn!("Écran OLED : erreur de flush (ignorée) : {:?}", e);
                    }
                }

                {
                    let mut donnees = etat.lock();
                    donnees.wifi_connecte = true;
                    donnees.wifi_ip = Some(ip_texte.clone());
                }
                _server = Some(web_server::demarrer(etat.clone(), journal.clone())?);
                wifi = Some(w);
            }
            Err(e) => {
                warn!(
                    "Wi-Fi : connexion initiale échouée, démarrage sans Wi-Fi (aucun impact sur la pompe/les sécurités) : {:?}",
                    e
                );
            }
        }
    } else {
        warn!("Wi-Fi désactivé (config::WIFI_ACTIF = false) : test temporaire, pas de serveur web, pas de synchro NTP, heure GPS uniquement.");
    }

    // Sonde de joignabilité réelle (ping périodique de la passerelle). Démarrée même
    // si la connexion initiale a échoué : elle reste inerte tant qu'aucune passerelle
    // ne lui est fournie, et se mettra à travailler dès la première connexion réussie.
    let sonde_reseau = if config::WIFI_ACTIF {
        match surveillance_reseau::Sonde::demarrer() {
            Ok(s) => Some(s),
            Err(e) => {
                warn!("Sonde réseau : démarrage impossible (surveillance désactivée) : {e:?}");
                None
            }
        }
    } else {
        None
    };

    // Dernières valeurs valides : conservées telles quelles en cas d'échec de lecture
    // ponctuel, plutôt que d'afficher une valeur manquante côté dashboard.
    let mut derniere_temperature_air: Option<f32> = None;
    let mut derniere_humidite: Option<f32> = None;

    // AHT10 : bloque ~80 ms à chaque lecture (temps de mesure du capteur). On ne
    // l'interroge donc pas à chaque tick, pour ne pas ralentir la réactivité du bouton
    // écran. Porté de 2 s à 10 s le 16/08/2026, en même temps que la sonde d'eau : la
    // température et l'humidité de l'air ne varient pas de façon perceptible en 2 s, et
    // ces 80 ms rendus à la boucle profitent au reste (bouton, GPS, pilotage pompe).
    const INTERVALLE_AHT10: Duration = Duration::from_secs(10);
    let mut dernier_aht10 = Instant::now() - INTERVALLE_AHT10;

    let mut sonde_eau = ds18b20::SondeEau::nouveau();

    let mut securite_moteur = securite::SecuriteMoteur::nouveau();
    let mut niveau_eau = niveau_eau::NiveauEau::nouveau();
    let mut filtre_mode = filtre_mode::FiltreMode::nouveau();
    let mut pompe = pompe::GestionPompe::nouveau();
    let mut filtration_auto = filtration_auto::FiltrationAuto::nouveau(&stockage);
    let mut boost = boost::Boost::nouveau(stockage.lire_u32(CLE_BOOST_MIN, 60));
    let mut dernier_jour: Option<u32> = None;
    let mut dernier_jour_texte: Option<String> = None;
    // Verrou de sécurité : une fois l'objectif d'heures du jour atteint, la filtration AUTO
    // ne redémarre plus tant que le jour n'a pas changé — même si `heures_cibles` remonte
    // ensuite suite à une variation de température (ex. chute brutale lors d'un orage), pour
    // éviter tout cyclage marche/arrêt répété sur le relais pompe.
    let mut filtration_terminee_aujourdhui = false;

    // Journal : suivi des sessions pompe (début/fin) et des alertes (front montant
    // de chaque condition), pour alimenter le bilan journalier.
    let mut session_debut: Option<(String, String, Instant)> = None;
    let mut pompe_precedent = false;
    // Détecte un changement d'état pompe pendant le bloc journal (verrouillé) ;
    // consommé juste après, une fois le verrou relâché, pour envoyer vers Adafruit IO
    // sans jamais bloquer le journal pendant l'appel réseau.
    let mut pompe_transition: Option<bool> = None;
    // Même principe que `pompe_transition`, pour le mode (AUTO/MANU/OFF) : détecté
    // près de `historique_modes`, consommé plus loin vers Adafruit IO une fois le
    // Wi-Fi connu.
    let mut mode_transition: Option<etat_partage::Mode> = None;
    let mut niveau_ok_precedent = true;
    let mut securite_actif_precedent = false;
    let mut sonde_muette_precedente = false;
    let mut pompe_bloquee_precedent = false;
    let mut anti_gel_precedent = false;
    let mut canicule_precedent = false;
    let mut pcf8574_ok_precedent = true;
    let mut alertes_jour: u32 = 0;
    // Au tout premier tour, les drapeaux "_precedent" ci-dessus valent tous `false`
    // par défaut, alors que l'état réel (ex. canicule déjà en cours avant un
    // redémarrage) peut déjà être vrai. Sans ce garde-fou, ça se lirait comme un
    // nouveau front montant et déclencherait une alerte en double juste après un
    // redémarrage à chaud, pour une condition qui n'a en réalité jamais cessé.
    let mut premier_tour_alertes = true;

    // Redémarrage : journalisé une seule fois, dès que l'heure locale est fiable
    // (nécessaire pour estimer la durée d'arrêt via l'horodatage sauvegardé en NVS).
    let dernier_horodatage_connu = stockage.lire_u32(CLE_DERNIER_HORODATAGE, 0);
    let mut redemarrage_journalise = false;
    let mut dernier_sauvegarde_horodatage = Instant::now() - Duration::from_secs(60);
    let mut dernier_sauvegarde_pompe_jour = Instant::now() - Duration::from_secs(60);

    // Historique coloré des modes pour la timeline du dashboard (portage de ModeHistory).
    let mut historique = historique_modes::HistoriqueModes::nouveau();
    let mut historique_initialise = false;
    let mut dernier_mode_physique = etat_partage::Mode::Off;
    // Dernier type de segment de timeline ouvert (0=OFF, 1=AUTO, 2=MANU_ON, 3=MANU_OFF,
    // 4=BOOST_ON, 5=BOOST_OFF) — sert à détecter tout changement (mode, marche/arrêt en
    // Manuel, ou Boost) qui doit fermer le segment en cours et en ouvrir un nouveau.
    let mut dernier_type_segment: Option<u8> = None;

    // Second historique, séparé du premier : la marche RÉELLE de la pompe (0=arrêtée,
    // 1=en marche), indépendamment du mode sélectionné — sert à tracer un trait fidèle
    // sur le dashboard plutôt que le bloc synthétique "Fait" actuel, toujours ancré à
    // l'heure de début de plage (voir l'échange du 29/07/2026 : un boost ayant tourné
    // cette nuit-là apparaissait à tort comme si la pompe avait tourné dès 8h00).
    let mut historique_pompe = historique_modes::HistoriqueModes::nouveau();
    let mut dernier_etat_pompe_segment: Option<u8> = None;

    // Écran OLED : 5 pages, bouton P4 pour naviguer.
    // 0=capteurs, 1=Wi-Fi, 2=pompe/filtration, 3=sécurités/uptime, 4=bilan journalier.
    const NB_PAGES: u8 = 5;
    const RETOUR_AUTO_APRES: Duration = Duration::from_secs(30);
    const APPUI_LONG: Duration = Duration::from_millis(800);
    const VEILLE_APRES: Duration = Duration::from_secs(300);

    let mut page_ecran: u8 = 0;
    let mut bouton_precedent = false;
    let mut appui_depuis: Option<Instant> = None;
    let mut appui_traite = false;
    let mut dernier_changement_page = Instant::now();
    let mut derniere_activite = Instant::now();
    let mut ecran_en_veille = false;
    let mut alerte_visible = true;
    let mut dernier_clignotement = Instant::now();
    let mut temp_min_jour: Option<f32> = None;
    let mut temp_max_jour: Option<f32> = None;

    // Redessin de l'écran : seulement quand quelque chose a changé (page, alerte,
    // veille, clignotement) ou au bout d'un intervalle périodique — le flush I2C du
    // framebuffer est la plus grosse transaction du bus, inutile de la refaire à chaque tick.
    const INTERVALLE_DESSIN: Duration = Duration::from_millis(500);
    let mut page_ecran_precedente: u8 = u8::MAX; // force le tout premier dessin
    let mut alerte_precedente = false;
    let mut veille_precedente = false;
    let mut dernier_dessin = Instant::now() - INTERVALLE_DESSIN;

    // Le journal série n'a pas besoin d'être mis à jour à chaque tick.
    //
    // Porté de 2 s à 10 s le 16/08/2026. Mesure faite sur une capture de 4 h 40 : la ligne
    // d'état représentait 8382 lignes sur 8847, soit 95 % du fichier et ~13 Mo par jour.
    // Or les capteurs ne sont relus que toutes les 10 s (voir `INTERVALLE_AHT10` et
    // `ds18b20::INTERVALLE_LECTURE`) : quatre lignes sur cinq recopiaient donc des valeurs
    // rigoureusement identiques. Le coût pour la carte était négligeable — 1,3 % du débit
    // série — mais un journal illisible ne sert à rien, et c'est justement ce qui avait
    // laissé passer inaperçue une valeur figée pendant des semaines.
    const INTERVALLE_LOG: Duration = Duration::from_secs(10);
    let mut dernier_log = Instant::now() - INTERVALLE_LOG;

    // À 10 s d'intervalle, l'instant exact d'une transition serait perdu. On journalise
    // donc aussi, immédiatement, dès qu'un état discret change — même principe périodique
    // + événementiel que pour les envois vers Adafruit IO. Ce sont les seules grandeurs
    // dont la date compte à la seconde près ; les températures, elles, dérivent lentement.
    let mut etats_precedents: Option<(bool, bool, bool, bool, bool)> = None;

    // --- Supervision réseau ---
    // Une seule machine à états (voir `surveillance_reseau.rs`) remplace les deux
    // mécanismes concurrents d'avant le 16/08/2026 : la reconnexion sur perte
    // d'association, et le chien de garde « zombie » sur taux de perte. Ils avaient des
    // compteurs indépendants, ce qui a coûté 1 h 30 de récupération lors de l'incident de
    // cette nuit-là au lieu des 25 minutes prévues. Le superviseur décide, la boucle agit.
    let mut superviseur_reseau = surveillance_reseau::Superviseur::nouveau();
    // Intervalle minimal entre deux redémarrages automatiques. Sans ce garde-fou, une
    // perturbation extérieure durable (interférence, box en panne) ferait redémarrer la
    // carte en boucle. Persisté en NVS, sinon le compteur serait remis à zéro par le
    // redémarrage qu'il est censé limiter.
    const INTERVALLE_MIN_REBOOT_AUTO: i64 = 60 * 60;

    // Envoi périodique des mesures vers Adafruit IO (cloud gratuit) : toutes les 5
    // minutes suffit largement (l'eau/l'air ne varient pas vite).
    const INTERVALLE_ENVOI_CLOUD: Duration = Duration::from_secs(300);
    let mut dernier_envoi_periodique = Instant::now();

    // Envois événementiels (pompe/mode) : marge de 16 s entre deux envois pour rester
    // raisonnable côté réseau. Si un changement survient trop tôt, il n'est pas perdu :
    // il reste en attente (`pompe_transition`/`mode_transition` non consommés) et part
    // dès que le délai est écoulé, avec la valeur la plus récente.
    const DELAI_MIN_EVENEMENT: Duration = Duration::from_secs(16);
    let mut dernier_envoi_evenement = Instant::now() - DELAI_MIN_EVENEMENT;
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

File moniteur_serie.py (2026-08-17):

"""Moniteur série sans reset pour l'ESP32 (projet piscine, c:\\rust\\3).

Contrairement à `espflash monitor --no-reset`, ce script fixe DTR et RTS à
`False` AVANT d'ouvrir le port : aucune impulsion n'est donc envoyée sur ces
lignes a la connexion, ce qui evite de declencher le circuit auto-reset de la
carte (condensateurs couples a EN/GPIO0) et de la coincer dans le bootloader
ROM (voir memoire "piege moniteur serie bootloader" - incident du 28/07/2026).

Utilisation : python moniteur_serie.py [PORT] [VITESSE] [DOSSIER_LOGS] [ETIQUETTE]
Par defaut : port COM4, vitesse 115200 (comme espflash), logs dans C:\\rust\\3\\logs.

Le troisieme argument permet de capturer une autre carte sans melanger les
journaux : depuis le 16/08/2026 une carte espion Wi-Fi (ESP32 sur COM7) tourne
en parallele de l'automate piscine, et il faut pouvoir comparer les deux points de
vue au meme instant. Voir l'alias PowerShell `connect` et sa cible `espion`.

Le quatrieme argument nomme la carte dans le fichier lui-meme :

    log_espion_2026-08-16_15h33_fonctionnement.txt

Les deux captures demarrant a une minute d'intervalle, leurs noms etaient quasi
identiques et seul le dossier les distinguait. Or des qu'un fichier est copie ou
ouvert dans un onglet d'editeur, ce contexte disparait. L'etiquette est placee juste
apres "log_" : comme tous les fichiers d'un meme dossier la partagent, le tri par
nom reste chronologique.

Ctrl+C pour quitter.
"""

import sys
from datetime import datetime
from pathlib import Path

import serial

PORT_PAR_DEFAUT = "COM4"
VITESSE_PAR_DEFAUT = 115200
# Dossier fixe, peu importe d'où `connect` est lancé (voir memoire "piege
# moniteur serie bootloader" et les echanges du 29/07/2026) - cree si absent.
DOSSIER_LOGS_PAR_DEFAUT = Path(r"C:\rust\3\logs")


def main() -> None:
    port = sys.argv[1] if len(sys.argv) > 1 else PORT_PAR_DEFAUT
    vitesse = int(sys.argv[2]) if len(sys.argv) > 2 else VITESSE_PAR_DEFAUT
    dossier_logs = Path(sys.argv[3]) if len(sys.argv) > 3 else DOSSIER_LOGS_PAR_DEFAUT
    etiquette = sys.argv[4] if len(sys.argv) > 4 else ""

    reponse = input("Enregistrer aussi dans un fichier ? (o/N) : ").strip().lower()
    fichier_fonctionnement = None
    fichier_defauts = None
    if reponse in ("o", "oui", "y", "yes"):
        dossier_logs.mkdir(parents=True, exist_ok=True)
        # Sans etiquette, on garde exactement l'ancien nommage : les captures ad hoc
        # (`connect COM5`) ne changent pas de forme.
        prefixe = "log_%s_" % etiquette if etiquette else "log_"
        base = datetime.now().strftime(prefixe + "%Y-%m-%d_%Hh%M")
        chemin_fonctionnement = dossier_logs / f"{base}_fonctionnement.txt"
        chemin_defauts = dossier_logs / f"{base}_defauts.txt"
        fichier_fonctionnement = open(chemin_fonctionnement, "w", encoding="utf-8")
        fichier_defauts = open(chemin_defauts, "w", encoding="utf-8")
        print(f"Enregistrement dans {chemin_fonctionnement} et {chemin_defauts}")

    ser = serial.Serial()
    ser.port = port
    ser.baudrate = vitesse
    ser.dtr = False
    ser.rts = False
    try:
        ser.open()
    except serial.SerialException as e:
        if "Accès refusé" in str(e) or "PermissionError" in str(e):
            print(f"{port} est déjà utilisé par une autre connexion (un autre terminal `connect` ouvert ?).")
        else:
            print(f"Impossible d'ouvrir {port} : {e}")
        sys.exit(1)

    print(f"Connecté sur {port} à {vitesse} bauds (DTR/RTS désactivés, pas de reset). Ctrl+C pour quitter.")

    try:
        while True:
            ligne = ser.readline()
            if ligne:
                texte = ligne.decode(errors="replace")
                print(texte, end="")
                # A l'ecran, tout reste mélangé comme avant. A l'enregistrement,
                # les lignes ESP-IDF commencant par W (avertissement) ou E (erreur)
                # partent dans le fichier "defauts", tout le reste (I = info,
                # bannieres de demarrage...) dans "fonctionnement".
                if texte[:1] in ("W", "E") and fichier_defauts:
                    fichier_defauts.write(texte)
                    fichier_defauts.flush()
                elif fichier_fonctionnement:
                    fichier_fonctionnement.write(texte)
                    fichier_fonctionnement.flush()
    except KeyboardInterrupt:
        print("\nArrêt du moniteur.")
    finally:
        ser.close()
        if fichier_fonctionnement:
            fichier_fonctionnement.close()
        if fichier_defauts:
            fichier_defauts.close()


if __name__ == "__main__":
    main()

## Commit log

2026-07-30 Sonde DS18B20 : envoi Adafruit IO groupé, retrait de ThingSpeak
    - Adafruit IO : les 7 mesures partent en une seule requête HTTP via
    l'API "Group Data", au lieu de 7 requêtes séparées, pour réduire la
    contention réseau qui aggravait les erreurs CRC de la sonde 1-Wire.
    - ThingSpeak retiré entièrement (préférence pour les graphiques
    Adafruit IO, et un service cloud de moins à faire tourner).
    - Timeline du dashboard : distinction réelle Manuel ON/OFF et Boost
    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
2026-07-30 README : ajoute un arbre de fichiers commenté
    Section "Organisation des fichiers" regroupant les modules par rôle
    (capteurs, pilotage, stockage/journalisation, réseau/interface), pour
    donner une vue d'ensemble sans avoir à redessiner un schéma à chaque
    changement.
2026-07-30 README : ajoute le schéma électronique du montage
    Schéma KiCad complet (docs/schema-electronique.png), avec une précision
    sur les deux blocs anticipés (carte SD, interrupteur de logs) déjà
    câblés mais pas encore pris en charge par le firmware.
2026-07-30 README : ajoute une capture d'écran du tableau de bord web
2026-08-01 CI : crée config.rs depuis config.example.rs avant compilation
    Le workflow échouait systématiquement (build/fmt/clippy) car config.rs,
    exclu de Git, n'existe jamais sur un checkout frais — main.rs ne
    compile pas sans lui.
2026-08-03 Dashboard simplifié, tolérance PCF8574, filtre interrupteur mode, correctifs Wi-Fi et cache dashboard
    - Dashboard simplifié en lecture seule (index_simple.html/script_simple.js),
    activable via config::DASHBOARD_SIMPLIFIE, pour un montage identique dédié
    à la simple consultation.
    - Tolérance aux pannes PCF8574 (init/écriture relais non bloquants) + alerte
    visible dans le journal et le dashboard.
    - Filtre anti-rebond sur l'interrupteur physique de mode (filtre_mode.rs),
    700 ms de confirmation.
    - Niveau d'eau : première lecture après démarrage appliquée immédiatement.
    - Retry sur les envois Adafruit IO (3 tentatives) et reconnexion Wi-Fi avec
    réinitialisation complète d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
    [config.example.rs, main.rs, pcf8574.rs]
2026-08-08 Wi-Fi : desactive la veille modem et ajoute une sonde de joignabilite
    Firmware v1.3. Deux causes racines corrigees apres une panne de 1h30 pendant
    laquelle la carte est restee associee au reseau mais totalement injoignable,
    retablie seulement par un reset manuel.
    - wifi.rs : esp_wifi_set_ps(WIFI_PS_NONE), reapplique apres chaque stop()/start()
    du pilote. La veille modem activee par defaut par ESP-IDF s'effondrait sous
    charge avec un signal moyen (-65 a -70 dBm). Mesure A/B en charge (deux clients
    interrogeant /sensors toutes les 2 s) : perte de paquets 75 % -> 0 %,
    ping 1627 ms -> 9 ms, HTTP jusqu'a 7,38 s avec un echec a 20 s -> 0,09 a 0,13 s.
    - surveillance_reseau.rs (nouveau) :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
    [config.example.rs, main.rs]
2026-08-09 Docs : schema electronique mis a jour (PNG + export SVG)
    Schema KiCad 10.0.0 du 02/08/2026, incluant les blocs recents : lecteur micro SD,
    pH-metre PH-4502C, mesure de tension batterie et lecture tension batterie solaire.
    Ajoute aussi l'export SVG (vectoriel, zoomable sans perte de qualite).
2026-08-09 README : affiche le nouveau schema et propose la version SVG
    Le README pointait sur docs/schema-electronique.png, qui montrait encore
    l'ancienne version. Le nouveau schema remplace donc ce fichier plutot que de
    cohabiter avec lui sous un nom versionne : un seul fichier de reference, jamais
    de doute sur celui qui fait foi.
    Le PNG reste l'image affichee (58 Ko, rendu fiable sur GitHub) et le SVG est
    propose en lien juste en dessous (968 Ko, vectoriel, zoomable sans perte pour
    lire les valeurs de composants).
    Description des blocs anticipes mise a jour : le pH-metre PH-4502C figure
    desormais au schema.
2026-08-09 README : lien SVG en plein ecran, zoomable
    Le lien relatif ouvrait la visionneuse GitHub, qui contraint l'image a la largeur
    de la page et empeche tout zoom utile — l'interet du vectoriel etait donc perdu.
    Remplace par l'adresse brute, qui ouvre le fichier comme un document a part
    entiere : Ctrl + molette zoome alors sans aucune perte, jusqu'a lire les valeurs
    des composants. La marche a suivre est indiquee dans le texte, car ce n'est pas
    evident pour un visiteur.
2026-08-16 Reseau : firmware 1.4 a 1.7 — sockets, sonde au taux de perte, agregation, second coeur
    Quatre versions accumulees depuis la 1.3, toutes flashees et validees par la mesure.
    1.4 — Serveur web : max_open_sockets 4 -> 7 (defaut d'ESP-IDF lui-meme) et
    CONFIG_LWIP_MAX_SOCKETS 10 -> 16, contrainte imposee par ESP-IDF. Un navigateur ouvre
    jusqu'a 6 connexions en parallele : les 4 places saturaient et bloquaient l'acceptation.
    Mesure : 7,04 s pour etablir une connexion sur /script.js -> 0,02 s apres.
    1.5 — Sonde reseau : critere passe de « aucun ping reussi » a un taux de reussite sur
    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
2026-08-16 Serveur web : revalidation par ETag sur la page et le script (firmware 1.8)
    La page (42 Ko) et le script (37 Ko) ne changent qu'au reflashage, mais etaient marques
    `max-age=30` : passe trente secondes, le navigateur jetait sa copie et redemandait les
    80 Ko. Or ce sont precisement ces gros transferts qui echouent quand la liaison perd des
    paquets — mesure du 15/08/2026 : /sensors (1,3 Ko) passait sans probleme pendant que la
    page complete etait coupee a 20 s.
    Ces deux routes passent en `Cache-Control: no-cache` accompagne d'un `ETag`. Le navigateur
    garde sa copie et se contente de demander « a-t-elle change ? » : reponse 304 d'environ
    200 octets tant que la version du firmware est la mem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
2026-08-16 ETag calcule depuis le contenu, et suppression du dashboard simplifie (firmware 1.9)
    Deux defauts releves en relecture de la 1.8.
    1. L'ETag etait construit depuis VERSION_FIRMWARE. Modifier index.html ou script.js et
    flasher sans incrementer la version aurait fige le cache de tous les navigateurs deja
    passes : ils auraient recu 304 indefiniment, et un rechargement ordinaire n'y aurait rien
    change. C'etait une regression vers l'incident du 02/08/2026, alors que la documentation
    de la fonction affirmait « Impossible de servir une page perimee ».
    La propriete reposait donc sur une discipline — penser a incrementer un numero — ce qui
    n'est pas acceptable pour une propriete de correction.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
    [config.example.rs]
2026-08-16 Corrections issues de la relecture complete du code (firmware 1.9)
    Trois defauts critiques releves en relisant l'integralite de src/.
    1. surveillance_reseau.rs — le superviseur ne pouvait jamais declencher son redemarrage.
    Fenetre d'observation incomplete, il accordait le « benefice du doute » et declarait le
    reseau utilisable. Or une reinitialisation du pilote provoque une reassociation, qui vide
    justement cette fenetre : le reseau etait donc juge bon pendant les 10 minutes de
    remplissage, et le chronometre d'indisponibilite efface au bout de 60 s. Le seuil de 10 min
    n'etait jamais atteint — le defaut du 16/08 que ce module devait corriger, simplement
    deplace.
    On ne devine plus : fe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
    [main.rs]
2026-08-17 Reseau (firmware 2.0), schemas KiCad, doc consommation/etage de puissance
    - wifi.rs/main.rs : forcer_reconnexion() force une vraie deconnexion avant
    de reconnecter, corrige un bug ou le pilote se croyait deja associe et
    ignorait les demandes de reconnexion (confirme par capture reseau).
    - moniteur_serie.py : etiquetage des fichiers de log (plusieurs cartes en
    parallele).
    - Ajout des schemas/PCB KiCad (conversion partielle en 3,3V).
    - Doc : bilan de consommation electrique, photo pour l'etage de puissance
    a venir, _PISCINE.md.
    [Gestion filtration piscine.kicad_pcb, Gestion filtration piscine.kicad_sch, Gestion piscine ESP32.kicad_pcb]

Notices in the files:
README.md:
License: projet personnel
